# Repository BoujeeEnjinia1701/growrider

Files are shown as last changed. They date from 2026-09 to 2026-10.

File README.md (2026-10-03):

# GrowRider

     

**Area:** Mobility and Logistics · **TRL:** 3 of 9 (proof of concept on paper) · **Value-engineering target:** USD 300 (estimated USD 311 with the helmet) · **Difficulty:** 2 of 5

Rugged, repairable children's bicycle with an adjustable frame that fits ages 6 to 14, puncture-proof tires, a coaster brake and a small rated rack, built from parts common to regional adult bicycles.

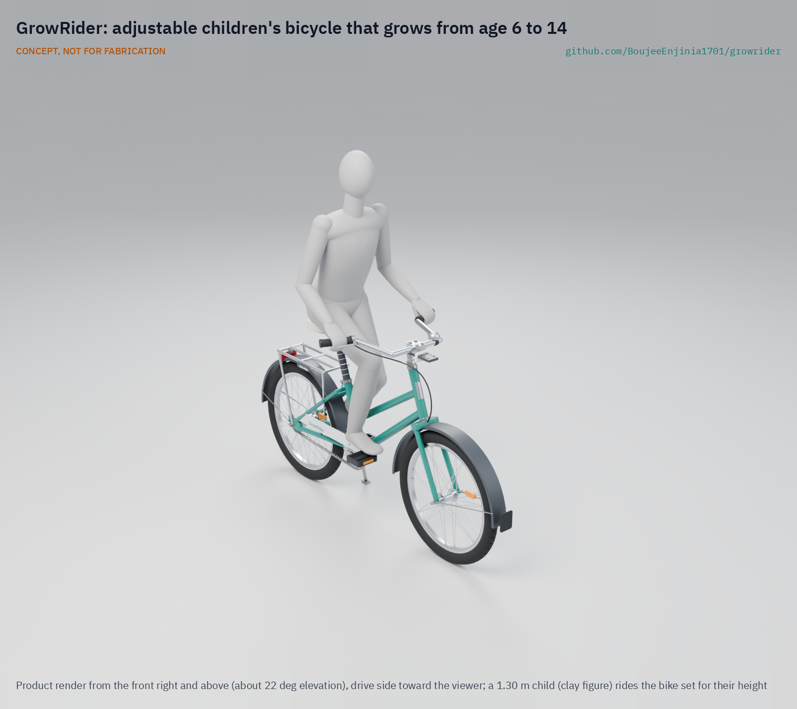
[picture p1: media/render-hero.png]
GrowRider: adjustable children's bicycle that grows from age 6 to 14, product render


[Exploded render](media/render-exploded.png) · [Detail render](media/render-detail.png) · [Interactive 3D model](media/viewer.html) · [Concept blueprint (PDF)](media/concept-blueprint.pdf) · [General arrangement GRR-DWG-001 (PDF)](cad/drawings/GRR-DWG-001.pdf) · [Sizing calculations](docs/04-calcs/01-sizing.md) · [Prototype build plan](docs/05-build-plan.md) · [Design decisions](docs/06-design-decisions.md) · [Review note](docs/REVIEW.md)

## Concept rationale

Children grow out of a fixed frame in two or three years, and in rural households one bicycle often has to serve several siblings over a decade. GrowRider answers that with adjustment instead of new frames: a two-stage telescoping seat post and a long quill stem stretch one 20 in step-through bicycle across riders from about 1.10 to 1.65 m, and the wear parts (chain, coaster hub internals, 1 in headset, 25.4 mm seat post, 9/16 in pedals) are the ones already sold for the region's adult roadsters, so any market mechanic can keep it running.

The design is open and garage-buildable because the people best placed to make and repair it are local frame builders and bicycle assemblers, not a distant factory. Publishing the geometry, the calculations and the bill of materials under CERN-OHL-S lets a school network, an NGO workshop or a regional assembler build it, change it for local parts and share the changes back.

## Burning platform

UNESCO reports that [251 million children and youth are out of school](https://www.unesco.org/en/articles/251m-children-and-youth-still-out-school-despite-decades-progress-unesco-report), that more than half of the world's out-of-school children and adolescents live in sub-Saharan Africa, and that 33 % of school-age children in low-income countries are out of school against 3 % in high-income countries. Distance is one of the barriers: in Bihar, India, a program that gave girls a bicycle to continue to secondary school raised their age-appropriate enrollment by 32 % and cut the gender gap by 40 %, with the largest effect in villages far from a school ([Muralidharan and Prakash, *American Economic Journal: Applied Economics*, 2017](https://www.aeaweb.org/articles?id=10.1257/app.20160004)).

The journey itself is dangerous. The World Health Organization reports that [road traffic injuries are the leading cause of death for children and young adults aged 5 to 29](https://www.who.int/news-room/fact-sheets/detail/road-traffic-injuries), with about 1.16 million road deaths a year, 92 % of them in low- and middle-income countries. A children's bicycle for these roads has to fit the child, stop reliably and be kept in repair, not just be cheap.

## Where it could be used

### By industry

| Industry | Use |
| --- | --- |
| Education | School bicycle fleets for rural primary and lower secondary pupils, loaned and refitted each year |
| Humanitarian and development NGOs | A children's model alongside existing adult roadster distribution and mechanic training |
| Bicycle assembly and retail | A regional children's frame built from roadster spares already in stock |
| Community health and social protection | Transport support bundled with school-feeding or cash-transfer programs |
| Local workshops and vocational training | A teaching project for frame building, wheel building and bicycle repair |

### By country or region

| Country or region | Why it matters there |
| --- | --- |
| Sub-Saharan Africa (for example Zambia, Kenya, Malawi) | More than half of the world's out-of-school children live in the region ([UNESCO](https://www.unesco.org/en/articles/251m-children-and-youth-still-out-school-despite-decades-progress-unesco-report)), and rugged adult roadsters and their spare-parts networks are already established |
| India (for example Bihar) | State bicycle programs for schoolgirls have measurably raised enrollment ([Muralidharan and Prakash, 2017](https://www.aeaweb.org/articles?id=10.1257/app.20160004)); younger pupils are not served by adult bicycles |
| Latin America (for example Bogotá, Colombia) | Bogotá's mobility and education departments run Al Colegio en Bici, which takes public-school pupils to school on guided cycle routes; in 2024 more than 9,000 students from 147 public schools used it and the city's other guided cycling and walking programs ([Alcaldía de Bogotá](https://bogota.gov.co/mi-ciudad/educacion/movilidad-en-bogota-al-colegio-en-bici-beneficios-para-estudiantes)). One adjustable frame could serve pupils of many sizes in such programs |
| Southeast Asia (for example Cambodia) | In July 2026, 200 donated bicycles went to pupils of five schools in Banteay Meanchey province, where many had walked several kilometres a day to class ([Agence Kampuchea Presse](https://www.akp.gov.kh/post/detail/374647)); a bicycle that grows with the child lasts longer in such donations |
| Netherlands and other high-income cycling countries | In a 2026 study of Dutch primary school children, 64 % cycled to school at least once a week ([Veldman, Westerbroek and Singh, *Transportation Research Interdisciplinary Perspectives*, 2026](https://doi.org/10.1016/j.trip.2026.101998)); an adjustable frame that is handed down suits families and school loan fleets and cuts the number of outgrown bikes |

## What sparked the idea

The starting point was the Chief Minister's Bicycle program in Bihar, India, launched in 2006, which gave every girl who enrolled in grade 9 Rs 2,000 (about $40) to buy a bicycle. Muralidharan and Prakash's evaluation ([*American Economic Journal: Applied Economics*, 2017](https://www.aeaweb.org/articles?id=10.1257/app.20160004); [NBER working paper 19305](https://www.nber.org/papers/w19305)) found that it raised girls' age-appropriate secondary enrollment by 32 % and worked best where the school was far from the village, so time and safety on the road were the barrier. The program reached teenagers entering secondary school, who can ride a standard bicycle. GrowRider asks what the same idea would need to reach the younger, smaller children who walk just as far: a frame that fits a six-year-old, grows to fit a fourteen-year-old, and is then handed down.

## Problem

Rural children often walk more than an hour each way to school, and adult bicycles do not fit them while imported children's bikes break quickly and cannot be repaired locally. Design with, not for: requirements must come from co-design sessions and field trials with the intended users through a local partner.

## Concept

Rugged, repairable children's bicycle with an adjustable frame that fits ages 6 to 14, puncture-proof tires, a coaster brake and a small rated rack, built from parts common to regional adult bicycles.

Full design precis: [docs/02-concept.md](docs/02-concept.md). The TRL 3 calculations ([GRR-CAL-001](docs/04-calcs/01-sizing.md)) find the fit range, reach, wheel size and rack meet their requirements on paper. With the recommendations Amish accepted on 2026-09-25 ([GRR-DDR-002](docs/decisions/0002-recommendations-accepted.md)), mass fell from 15.3 to 14.4 kg; with the parts added to make the design buildable ([GRR-DDR-003](docs/decisions/0003-design-for-construction.md)) it is 15.1 kg against the 13 kg production goal and still not met. Value-engineering target: USD 300. Estimated cost of the constructable design: USD 311 with the child helmet supplied with every bike (USD 11 over the target), USD 299 for the bike alone (USD 1 under). Braking margins for the smallest rider, the fit-change time and steerer strength are at risk.

## Key components

- Step-through frame with chromoly main tubes, a two-stage telescoping seat post (saddle 400 to 670 mm) and a long chromoly quill stem
- 20 in (ISO 406) alloy-rim wheels with solid puncture-proof tires
- Coaster brake hub plus front rim brake
- 140 mm cranks
- Single-speed chain drive
- Aluminium rear rack, rated 10 kg
- Reflectors and bell

The priced bill of materials is in [bom/bom.csv](bom/bom.csv): USD 311 with the child helmet supplied with every bike and USD 299 for the bike alone, against a USD 300 value-engineering target. The parametric model is [cad/src/model.py](cad/src/model.py), with STEP files in `cad/step/`.

## Building the prototype

The [prototype build plan](docs/05-build-plan.md) (GRR-BLD-001) shows how to make each of the eight made components, from the rear dropouts and the brazed chromoly frame to the slotted seat post, the quill stem with its head plate and the welded aluminium rack, and how to put all 24 components together in 17 steps, each with a picture drawn from the model. Making the concept buildable added track-end dropouts, stop screws in the seat post collars, a two-position bar clamp on a head plate and fixings for the rack, fenders, kickstand and chainguard, recorded in [GRR-DDR-003](docs/decisions/0003-design-for-construction.md). A local frame builder can make the components and any bicycle mechanic can assemble them. Decisions still open are in the [design decisions register](docs/06-design-decisions.md). Nobody may ride the prototype until it has passed the ISO 4210-2 tests.

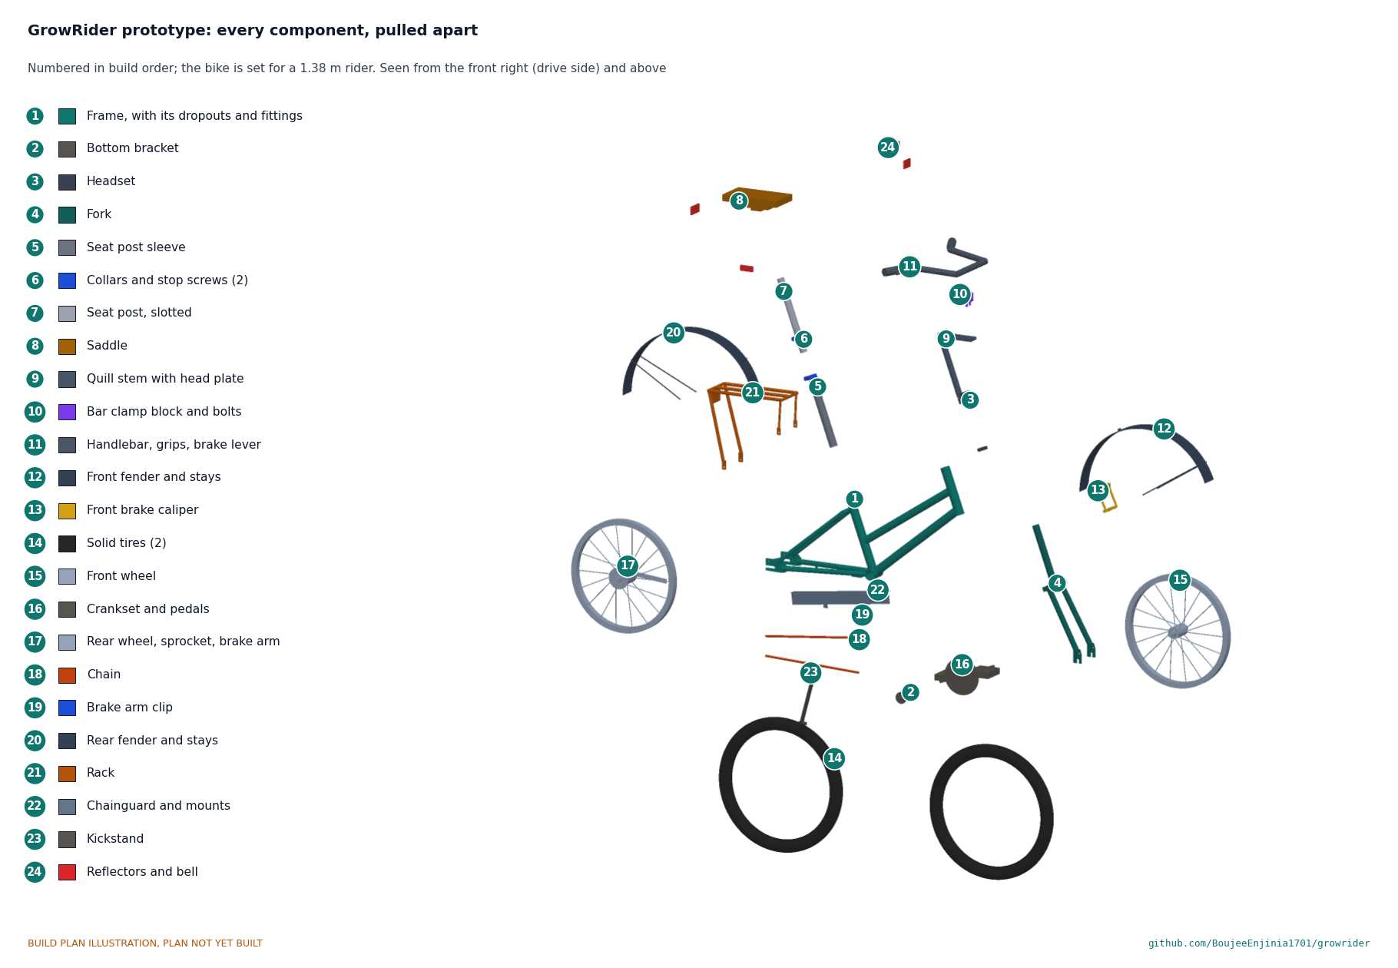
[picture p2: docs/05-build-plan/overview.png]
GrowRider prototype: every component, pulled apart and numbered in build order


## Safety

> **Safety:** Nothing has been built or tested. Rack load is limited to 10 kg for child safety. Frame, fork, seat post, stem and brakes must pass the tests of ISO 4210-2 (the standard that applies by saddle height) before anyone rides it.

## Repository layout

| Folder | Contents |
| --- | --- |
| `docs/` | Problem, concept, requirements, calculations and design decisions |
| `cad/src/` | build123d Python source, the source of truth for all geometry |
| `cad/step/`, `cad/stl/` | Exported models for FreeCAD, other CAD tools and printing |
| `cad/drawings/` | 2D sketches and dimensioned drawings |
| `bom/` | Bill of materials |
| `electronics/` | KiCad schematics and PCB layouts |
| `firmware/` | Microcontroller code |
| `media/` | Renders, perspectives and photos |
| `build-log/` | Dated prototyping notes |

## Documentation

Controlled documents follow the portfolio [documentation standard](.kit/STANDARDS.md). Each carries a document ID (GRR-PRC-001 for the precis), a version and a revision history. Branded PDFs are built with `python .kit/render.py` and attached to GitHub Releases when a document is tagged, for example `GRR-PRC-001/v1.0`.

## Credits

Designed by Amish Chadha. See [CONTRIBUTORS.md](CONTRIBUTORS.md) for roles. To cite this design, use [CITATION.cff](CITATION.cff) (GitHub shows it as "Cite this repository").

AI assistance (Claude) was used to accelerate concept renders, prototype documentation and first-pass sizing calculations. Design direction and all decisions are Amish Chadha's, recorded in this repository's decision records (`docs/decisions/`).

## Licenses

- **Hardware** (CAD, drawings, BOM, electronics): [CERN-OHL-S v2](LICENSE)
- **Software** (firmware, scripts, notebooks): [MIT](LICENSE-SOFTWARE)

A project of the [Design Molecule](https://designmolecule.com) lab.

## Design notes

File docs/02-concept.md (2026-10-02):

---
doc_id: GRR-PRC-001
title: GrowRider design precis
project: GrowRider
doc_type: Design precis
version: "0.8"
status: Draft
date: '2026-10-02'
author: Amish Chadha
license: CERN-OHL-S-2.0
revisions:
- version: "0.1"
  date: '2026-09-24'
  author: Amish Chadha
  change: Initial scaffold
- version: "0.2"
  date: '2026-09-24'
  author: Amish Chadha
  change: Populate to TRL 2 (architecture, first-order numbers, design choices, safety, media)
- version: "0.3"
  date: '2026-09-25'
  author: Amish Chadha
  change: TRL 3 (decisions of GRR-DDR-001 recorded; numbers replaced by GRR-CAL-001; seat post, stem and head tube sized; model, drawing GRR-DWG-001 and media updated)
- version: "0.4"
  date: '2026-09-25'
  author: Amish Chadha
  change: Recommendations accepted by Amish (DDR-002)
- version: "0.5"
  date: '2026-09-26'
  author: Amish Chadha
  change: Budget top-up approved by Amish
- version: "0.6"
  date: '2026-10-01'
  author: Amish Chadha
  change: Constructable design (GRR-DDR-003); cost stated against the value-engineering target
- version: "0.7"
  date: '2026-10-01'
  author: Amish Chadha
  change: GRR-DDR-003 accepted by Amish; quill insertion mark with a bright painted band, painted height scales, frame color and chainguard name as decided
- version: "0.8"
  date: '2026-10-02'
  author: Amish Chadha
  change: Helmet supplied with every bike, World Bicycle Relief as first candidate partner and Zambia as first candidate region, as decided by Amish on 2026-10-02 (GRR-DEC-001 v0.3)
---

# GrowRider design precis

GrowRider is a step-through chromoly steel children's bicycle on 20 in wheels whose seat post and stem telescope, so one bike fits riders from about 1.10 to 1.65 m (ages about 6 to 14) and can be handed down between siblings. It uses a coaster brake plus a front rim brake, puncture-proof tires, a single-speed chain drive and a small rack rated 10 kg, with wear parts shared with the region's adult roadsters. The calculation note GRR-CAL-001 v0.4 shows on paper that the fit range, reach, wheel size and rack meet their requirements; mass (about 15.1 kg against the 13 kg production goal) is not met; against the USD 300 value-engineering target, the constructable design is estimated at USD 299 for the bike (USD 1 under) and USD 311 with the helmet (USD 11 over), and the production cost is not yet estimated; and braking margins for the smallest rider, the fit-change time and steerer strength are at risk. Wheel size, brakes, frame type, tires and crank length were decided by Amish on 2026-09-25 (GRR-DDR-001), and on the same day he accepted the TRL 3 recommendations: chromoly main tubes, steerer, quill and sleeve, an aluminium rack, alloy rims and bar, a wider R2 and a split R9 (GRR-DDR-002). The design was made constructable on 2026-10-01 (GRR-DDR-003, accepted by Amish on 2026-10-01), and the prototype build plan is GRR-BLD-001 (`docs/05-build-plan.md`).

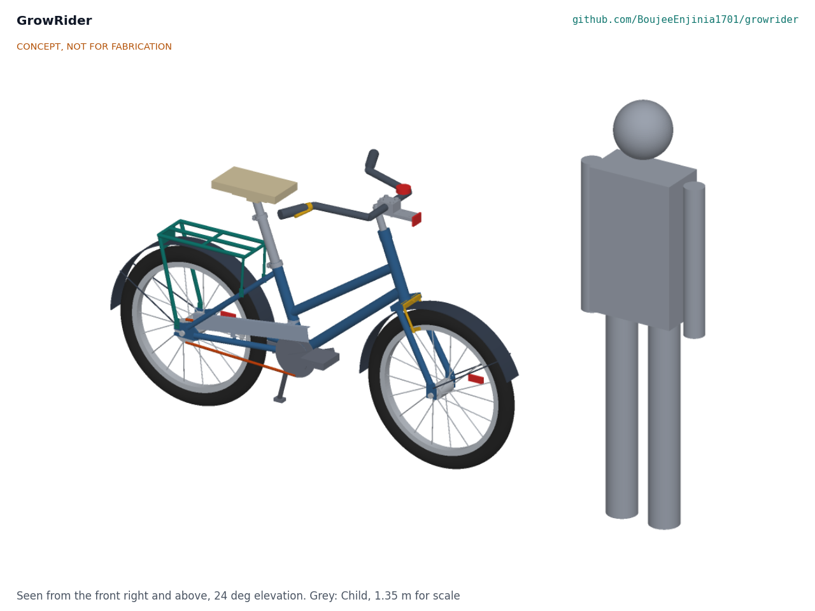
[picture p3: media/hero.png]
Hero render


*Figure 1. GrowRider parametric model (`cad/src/model.py`) set for a 1.38 m rider, beside a 1.35 m child (about 10 years old) for scale.*

## How it works

1. **Fit the rider.** A parent, teacher or mechanic sets saddle height with a two-stage telescoping seat post (a 29.2 x 1.8 mm chromoly sleeve that slides 130 mm in the 31.8 mm seat tube, then a standard 25.4 mm seat post that slides 140 mm in the sleeve) and sets handlebar height with a long 22.0 mm quill stem that slides 120 mm in the 1 in fork steerer; the bar clamp bolts to the quill's head plate 45 or 105 mm ahead of the steering axis. Each sliding part keeps at least 100 mm of insertion, shown by a permanent mark; on both seat post stages a stop screw in the clamp collar, riding in a slot, stops the part at that point. All the fit clamps use 13 mm bolts.
2. **Ride to school.** The rider pedals a single-speed chain drive (32T chainring, 18T sprocket, 140 mm cranks) at about 65 rpm for 11 km/h. Solid or airless tires cannot go flat on thorns.
3. **Stop.** Pedaling backward engages the coaster brake in the rear hub. A front rim brake with a short-reach lever gives a second, independent brake that still works if the chain comes off.
4. **Carry a school bag.** A small rear rack, rated and marked 10 kg, carries a bag or books. It is sized for a bag, not a passenger or a water container.
5. **Grow and hand down.** As the child grows, the post and stem are raised. When the child moves to an adult roadster, both are lowered and the bike passes to a younger sibling. Worn parts are replaced from the roadster parts already sold in the local market.

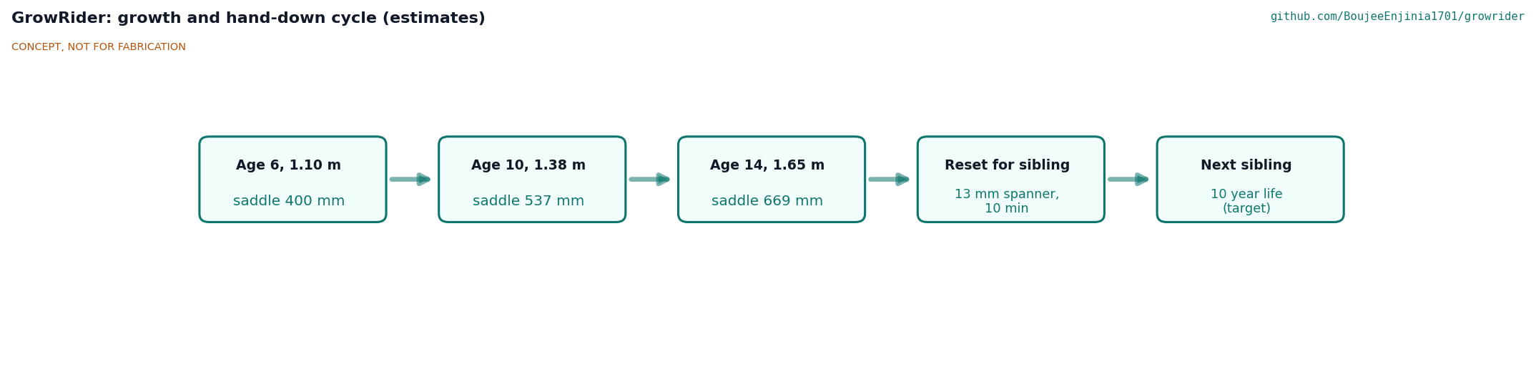
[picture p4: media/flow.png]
Growth and hand-down cycle


*Figure 2. Growth and hand-down cycle. Saddle heights are estimates from the crank-corrected fit rule in GRR-CAL-001, Table 2; the 10-year life is a target.*

## Main components

Item numbers match the exploded view (Figure 3) and `bom/bom.csv`.

| # | Component | Choice | Notes |
| --- | --- | --- | --- |
| 1 | Frame | Step-through frame with twin down tubes; chromoly 4130 main tubes: 31.8 x 1.2 mm seat tube, 280 mm long; 31.8 x 0.9 mm down tube; 28.6 x 0.9 mm loop tube; 180 mm head tube; steel stays | Decided 2026-09-25 (D3, D7). Low stepping point (455 mm) for small riders and school skirts |
| 2 | Fork | 20 in fork, 30 mm offset, crown about 16 mm deep, slotted fork ends 100 mm apart, 1 in threaded chromoly steerer with 220 mm usable above the crown (D10) | Standard 1 in headset as on roadsters; steerer longer than a stock 20 in fork |
| 3 | Telescoping seat post | 29.2 x 1.8 mm chromoly sleeve, 250 mm long (D10), plus 25.4 mm seat post, 280 mm long | 270 mm of travel in two stages (130 and 140 mm); saddle 400 to 670 mm from the BB |
| 4 | Saddle | Child size, light color cover | Light color stays cooler in sun |
| 5 | Telescoping stem | Long 22.0 mm chromoly quill (240 mm), 120 mm travel, welded head plate with a bolt-on bar clamp block at 45 or 105 mm ahead of the steering axis | Adjusts bar height (113 mm) and reach |
| 6 | Handlebar and grips | 22.2 mm alloy swept-back bar (D7), 520 mm wide, 160 mm sweep | Upright position for visibility |
| 7 | Front wheel | 20 in (ISO 406) alloy rim (D8), 28 spokes, nutted axle | Decided 2026-09-25 (D1); 15 mm axle nuts as on roadsters |
| 8 | Rear wheel | 20 in (ISO 406) alloy rim (D7) with coaster brake hub | Hub type widely used on regional roadsters (to confirm) |
| 9 | Tires (2) | 20 x 1.95 in solid or airless | Decided 2026-09-25 (D4) |
| 10 | Crankset | 140 mm cranks, 32T ring, 9/16 in pedal threads | One length decided 2026-09-25 (D5); adult pedals fit |
| 11 | Chain and sprocket | 1/2 x 1/8 in chain, 18T sprocket | Same chain as roadsters |
| 12 | Front brake | Side-pull caliper, short-reach adjustable lever | Second, independent brake; decided 2026-09-25 (D2) |
| 13 | Rear rack | 12 x 1.5 mm aluminium 6061-T6 tube (D7), 300 x 120 mm platform at 545 mm, 10 kg marked | No footrests or passenger seat |
| 14 | Fenders | Pair, full coverage | Rainy-season mud and school uniforms |
| 15 | Chainguard | Full plate over the upper chain run | Keeps clothing out of the chain |
| 16 | Kickstand | Rear-mounted | Parking at school |
| 17 | Reflectors and bell | Front white, rear red, spoke and pedal reflectors, bell | Road visibility |

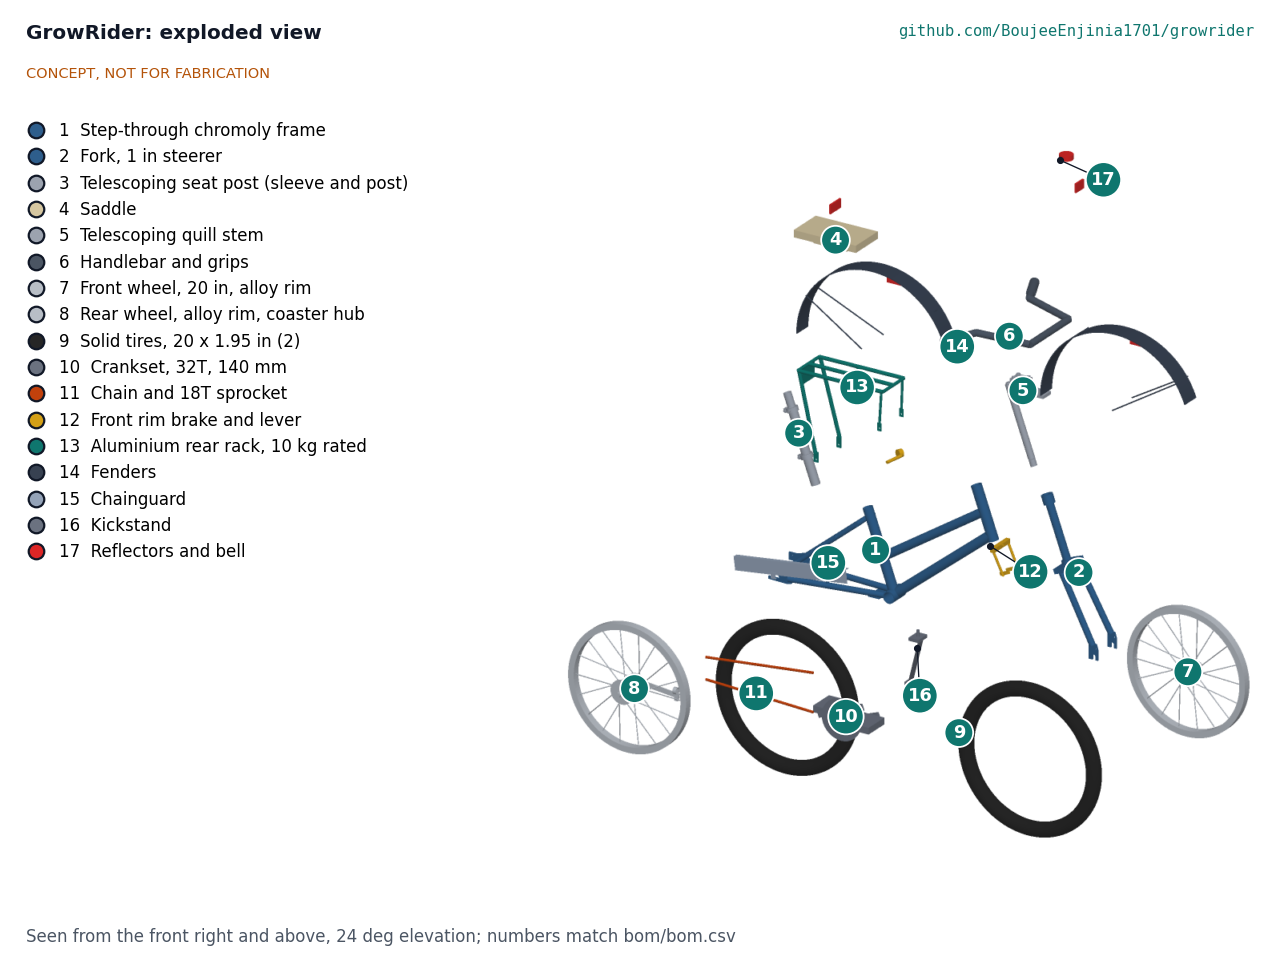
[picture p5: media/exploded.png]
Exploded view


*Figure 3. Exploded view with item numbers matching the BOM. The bottom bracket, headset, hardware and helmet (BOM lines 18 to 20) are not modeled.*

## Key numbers

All values come from the calculation note GRR-CAL-001 v0.3 and its script `docs/04-calcs/sizing.py`; they are paper estimates. The general arrangement is drawing GRR-DWG-001 (`cad/drawings/GRR-DWG-001.pdf`).

**Fit.** Assumptions: inseam is about 0.45 times standing height. Rule A sets saddle height (BB center to saddle top) at 0.88 times inseam; rule B sets saddle top to pedal at the bottom of the stroke at 1.09 times inseam, which accounts for the 140 mm crank. The design covers both.

| Rider height | Inseam (0.45 x height) | Saddle height, rule A | Saddle height, rule B |
| --- | --- | --- | --- |
| 1.10 m (about age 6) | 495 mm | 436 mm | 400 mm |
| 1.38 m (about age 10) | 621 mm | 546 mm | 537 mm |
| 1.65 m (about age 14) | 742 mm | 653 mm | 669 mm |

Table 1. Saddle height across the fit range (GRR-CAL-001, Table 2).

| Quantity | Value | Basis | Requirement |
| --- | --- | --- | --- |
| Saddle height range | 400 to 670 mm (270 mm) | Two stages of 130 and 140 mm, 100 mm insertion each | R2 met |
| Saddle rise and setback over the range | 254 mm up, 92 mm back | 270 mm along a 70° seat axis | |
| Handlebar height range | 113 mm | 120 mm of quill travel along a 70° steering axis | R3 met |
| Reach adjustment | 141 mm (241 mm shortest, 382 mm longest) | Seat and steering geometry, two bar clamp positions 60 mm apart, ±15 mm saddle rail | R3 met; shortest is 21 mm above the 220 mm placeholder for a 1.10 m rider |
| Standover at the stepping point | 455 mm | Loop tube top 100 mm ahead of its seat-tube joint | R1 met; 40 mm below a 1.10 m rider's inseam |
| Saddle top above ground | 636 to 890 mm | 260 mm BB height | Classifies the bike under ISO 4210-2 (city and trekking) |
| Grips relative to saddle | +128 mm (smallest) to -13 mm (largest) | 180 mm head tube needed for quill insertion | Very upright for small riders |
| Trail | 59 mm | 70° head angle, 30 mm fork offset | |
| Pedal clearance | 109 mm; strike at about 32° lean | 260 mm BB, 140 mm cranks | |
| Toe overlap | None (1.10 m) to 19 mm (1.65 m) with the bar turned | 480 mm front center | Tell riders |
| Gear development | 2.79 m per crank turn | 32/18 on a 1.57 m rolling circumference | 66 rpm at 11 km/h |
| Power on the level at 11 km/h | 26 to 51 W (34 W at 1.38 m) | Rolling coefficient 0.02 (solid tire on gravel), CdA 0.35 m² | Sustainable for a child |
| Power on a 5 % climb at 7 km/h | 47 to 102 W (64 W at 1.38 m) | Same, plus gravity | Short climbs only; steep hills walked |
| Mass | 15.1 kg (14.4 kg before GRR-DDR-003, 15.3 kg before GRR-DDR-002) | Frame 2.67 kg from the model's tubes and fittings, stem 0.90 kg, wheels 2.75, solid tires 2.2, drive 1.45, rack 0.44, other parts 5.1 kg | **R5 (13 kg production goal) not met** |
| Rear coaster brake alone, grip limit | 0.26 to 0.28 g dry, 0.19 g on loose gravel | μ (L - x) / (L + μh) with the rider-plus-bike mass center | Front brake needed on gravel |
| Coaster brake, smallest rider | 0.22 g | 85 N back-pedal force needed for 0.2 g, about 93 N available (assumed hub brake ratio 2.5) | R7 at risk |
| Front rim brake, smallest rider | 0.24 g dry; about 0.14 g wet with the alloy rim (0.05 g with steel) | 33 N lever force for 0.2 g dry, 40 N assumed | R7 at risk; alloy rim decided (D8) |
| Both brakes, dry | 0.46 to 0.57 g | Sum, capped by grip and pitch-over (0.57 to 0.81 g) | R7 target 0.35 g met on paper |
| Rack | 10 kg; 26 MPa in the aluminium rails at 2.5 g (110 MPa welded 6061-T6) | 300 x 120 mm platform; front wheel load falls from 40 % to 32 % with 10 kg for the smallest rider | R6 met |
| Strength screen | 1 of 7 sections above its screen: steerer at the crown in hard braking (117 MPa against 90 MPa for chromoly); sleeve 61 MPa, quill 79 MPa, head plate 71 MPa and seat tube 72 MPa pass (3 of 6 above before GRR-DDR-002) | Largest rider, largest setting | R12 at risk |
| Prototype parts cost | USD 311 with the helmet supplied with every bike, USD 299 for the bike alone (USD 293 and 281 before GRR-DDR-003) | `bom/bom.csv` | Value-engineering target USD 300: bike USD 1 under, with helmet USD 11 over; R11 at risk until production cost is estimated |

**Commute time.** Assumptions: a 5 km trip each way; walking at 4 to 5 km/h; cycling at 10 to 12 km/h on dirt roads.

| Mode | Speed | One way | Round trip |
| --- | --- | --- | --- |
| Walking | 4 to 5 km/h | 60 to 75 min | 2.0 to 2.5 h |
| GrowRider | 10 to 12 km/h | 25 to 30 min | 50 to 60 min |
| Time returned to the child | | 30 to 50 min | 60 to 100 min per day; about 79 min per day and 249 h per 190-day school year at the midpoints |

Table 2. School trip time, walking and cycling (estimates).

## Key design choices

- **Wheel size: 20 in (ISO 406).** 20 in keeps standover at 455 mm so a 1.10 m child can stand over the frame, and gives lower mass. 24 in (ISO 507) rolls better on ruts but raises standover to about 510 mm and fails R1 for the smallest riders. Neither is a regional roadster size, so tires and rims are the one commonality gap either way. Decided by Amish, 2026-09-25 (GRR-DDR-001, D1).
- **Brakes: coaster brake plus front rim brake.** A coaster brake is simple, weather-proof, needs no hand strength, and uses hub internals common on regional roadsters. On its own it fails completely if the chain comes off and is marginal on loose gravel (about 0.19 g). Adding a front rim brake gives two independent brakes. Alternatives: coaster only (cheaper, one failure mode away from no brake) or two hand brakes without a coaster (needs hand strength small children may lack). Decided by Amish, 2026-09-25: coaster plus front rim brake (GRR-DDR-001, D2). GRR-CAL-001 finds the smallest rider's margins small and a wet steel rim nearly useless, so an alloy front rim was decided (GRR-DDR-002, D8), and the coaster hub's brake ratio is to be obtained before further brake work (D9).
- **Step-through frame.** Lower standover than a diamond frame, and practical for school uniforms and skirts. It needs twin down tubes to keep the frame stiff. Decided by Amish, 2026-09-25 (GRR-DDR-001, D3).
- **Mass and materials.** Chromoly 4130 main tubes, an aluminium rack, alloy rims and an alloy bar, keeping the solid tires, with 13 kg kept as the production goal. Decided by Amish, 2026-09-25: go with recommendation (GRR-DDR-002, D7). The result was 14.4 kg, not the 13.6 kg first estimated, and it added USD 38 to the prototype; with the parts added for construction (GRR-DDR-003) the bike is 15.1 kg.
- **Sliding parts and steerer.** Chromoly steerer and quill and a 29.2 x 1.8 mm chromoly sleeve, which needs a 1.2 mm seat tube wall to fit. Decided by Amish, 2026-09-25: go with recommendation (GRR-DDR-002, D10). The steerer is still above its screen in hard braking; a 2.0 mm wall is proposed (N2).
- **Puncture-proof tires.** Solid or airless tires remove thorn punctures entirely but add about 0.5 kg for the pair (GRR-CAL-001), ride harsher and roll less freely. Thorn-resistant tubes with tire liners keep standard parts and a softer ride, but still puncture occasionally. Decided by Amish, 2026-09-25: solid or airless for the prototype, and ask users in co-design (GRR-DDR-001, D4).
- **Parts commonality.** Chain, coaster hub internals, 1 in headset, 25.4 mm seat post, 22.2 mm handlebar and 9/16 in pedal threads are chosen to match adult roadster parts. Children's bikes often use 1/2 in pedal threads; GrowRider does not.
- **Head tube and steerer length.** A 180 mm head tube and 30 mm headset stack give the quill 220 mm of steerer, enough for 120 mm of travel with 100 mm of insertion at full height. The cost is a high bar for the smallest rider (128 mm above the saddle).
- **Bolted clamps, not quick releases.** 13 mm bolts discourage casual changes and theft of the seat post, and every mechanic already has the spanner.

## Safety

> **Safety:** GrowRider is ridden by children on roads shared with trucks and motorbikes. It is a concept. No part of it has been built or tested, and it must not be ridden until the frame, fork, sliding joints, rack and brakes have passed the tests of the applicable standard (ISO 8098 or ISO 4210) at a later TRL.

- **Brakes.** Two independent brakes are required (R7). The coaster brake stops working if the chain comes off, so the front brake is not optional. Small hands need a short-reach lever. Riders need to be shown that a hard front brake on loose gravel can skid the front wheel. A wet steel rim gives a child almost no front braking (about 0.05 g), so an alloy rim is specified (about 0.14 g wet).
- **Telescoping parts.** A seat post or stem raised past its minimum insertion can break or pull out. Every sliding part carries a permanent minimum insertion mark at 100 mm. On the sleeve and the seat post a stop screw in the clamp collar, riding in a slot, stops the part at that point (GRR-DDR-003, P8). The quill cannot take a stop of this kind inside a threaded steerer, so for the prototype its minimum insertion mark, with a bright painted band above it, is its only limit, checked at every fit change; a clamp-on stop collar is to be considered after the fit trials (decided by Amish, 2026-10-01, GRR-DEC-001). Painted height scales on the exposed sleeve and quill let a setting be noted and reset. At full extension the sleeve and quill are the most stressed sections (GRR-CAL-001, section K). Clamp slots are pinch points for fingers.
- **Rack limit.** The rack is rated 10 kg and marked. It must not carry passengers, water containers or goods above the rating: a heavy load high over the rear wheel makes a light bike hard for a child to steer and can lift the front wheel. The rack is sized for a school bag, with no footrests.
- **Road visibility.** School trips often start and end near dawn or dusk. Front white, rear red, spoke and pedal reflectors are fitted. The portfolio renders use the kit teal; the production frame color is settled in co-design, with a high-visibility option (decided by Amish, 2026-10-01). A light (for example a hub dynamo) is suggested for a later version.
- **Helmet.** An adjustable, ventilated child helmet is supplied with every bike through the partner program and fitted at handover (BOM line 20; decided by Amish, 2026-10-02, GRR-DEC-001). Hot-climate comfort will decide whether it is worn, so how it is worn is discussed in co-design.
- **Aluminium rack.** Welded aluminium has a low fatigue strength and cracks without warning; the rack must pass static and fatigue tests before use, and the 10 kg rating marking matters more than before.
- **Clothing and hot surfaces.** The chainguard keeps skirts and trousers out of the chain. A light saddle cover limits heating in the sun.
- **Mass.** At about 15.1 kg, the bike is about 80 % of the weight of a 19 kg six-year-old. This makes pushing, lifting and controlling a fall harder for the smallest riders, and is the reason R5 matters.

## Open questions

- Reduce mass toward the 13 kg production goal: with chromoly, aluminium and alloy parts adopted (D7) and the parts added for construction (GRR-DDR-003), the bike is 15.1 kg. The remaining option, pneumatic tires with liners (0.5 kg), would reverse D4. Can local frame builders work chromoly and weld aluminium, and are the lighter parts stocked?
- Low bar option: would a flat bar suit the smallest riders, whose grips sit 128 mm above the saddle? A co-design question (GRR-DDR-002, D13).
- Sliding joints in dust and rain: will greased steel sleeves seize over years of use? Would a split collar with a wiper seal or a plastic bushing help?
- Crank length: one 140 mm length for the prototype was decided on 2026-09-25 (D5). It is 0.28 of a 1.10 m rider's inseam; the 127 mm swap remains a later option.
- Standard: by maximum saddle height (890 mm) GrowRider falls under ISO 4210-2 (city and trekking). Its test loads assume adult riders; whether to also meet ISO 8098 limits for the small settings needs the standards' text.
- Confirm with a partner which roadster parts are actually stocked in the target region, including coaster hubs and 20 in tires. World Bicycle Relief is the first candidate partner to approach and Zambia the first candidate region (decided by Amish, 2026-10-02, GRR-DEC-001).
- Test the anthropometric assumptions (inseam ratio, reach) with measurements of children in the target region, where average heights may be below global references.

Concept media: [blueprint sheet](../media/concept-blueprint.pdf), [interactive 3D model](../media/viewer.html).

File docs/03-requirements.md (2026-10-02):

---
doc_id: GRR-REQ-001
title: GrowRider requirements
project: GrowRider
doc_type: Requirements
version: "0.7"
status: Draft
date: '2026-10-02'
author: Amish Chadha
license: CERN-OHL-S-2.0
revisions:
- version: "0.1"
  date: '2026-09-24'
  author: Amish Chadha
  change: Initial scaffold
- version: "0.2"
  date: '2026-09-24'
  author: Amish Chadha
  change: First measurable requirements for TRL 2
- version: "0.3"
  date: '2026-09-25'
  author: Amish Chadha
  change: Record decisions of GRR-DDR-001 (20 in wheels, brakes, $120 production target); add TRL 3 status from GRR-CAL-001
- version: "0.4"
  date: '2026-09-25'
  author: Amish Chadha
  change: Recommendations accepted by Amish (DDR-002)
- version: "0.5"
  date: '2026-09-26'
  author: Amish Chadha
  change: Budget top-up approved by Amish
- version: "0.6"
  date: '2026-10-01'
  author: Amish Chadha
  change: Status figures from GRR-CAL-001 v0.4 (constructable design, GRR-DDR-003); R11 stated against the value-engineering target
- version: "0.7"
  date: '2026-10-02'
  author: Amish Chadha
  change: R11 status reports USD 311 with the helmet, now supplied with every bike (decided by Amish, 2026-10-02), as the prototype figure
---

# GrowRider requirements

These are the requirements for the concept. They were checked by calculation at TRL 3 in GRR-CAL-001 v0.4, on the constructable design of GRR-DDR-003: 5 are met on paper, 1 is not met (R5, mass), 4 are at risk and 2 cannot be verified at TRL 3. Amish's acceptance of the TRL 3 recommendations on 2026-09-25 (GRR-DDR-002) widened R2 to the crank-corrected fit range, split R9 into parent and mechanic tool lists, restated R5 as the production goal and named the alloy front rim in R7. All targets must still be revised from co-design findings before the design is frozen (see GRR-PRB-001).

| ID | Requirement | Target | Verification (TRL 3 or later) | TRL 3 status (GRR-CAL-001) |
| --- | --- | --- | --- | --- |
| R1 | Fit the intended riders | Rider height 1.10 to 1.65 m (ages about 6 to 14); standover height 470 mm or less at the stepping point | Fit calculation from anthropometric data; later fit trials with children | Met: standover 455 mm |
| R2 | Adjustable saddle height | 400 to 670 mm from bottom bracket center to saddle top (270 mm range), with at least 100 mm insertion at every sliding joint across the range (widened from 436 to 654 mm, GRR-DDR-002, D11) | Geometry calculation; massing model | Met: 400 to 670 mm, 100 mm insertion |
| R3 | Adjustable reach and handlebar height | Handlebar height adjustable by 100 mm or more; horizontal saddle-to-grip reach adjustable by 100 mm or more | Geometry calculation | Met: bar 113 mm, reach 141 mm |
| R4 | One wheel size across the whole fit range | Single wheel size for all riders: 20 in (ISO 406), decided 2026-09-25 (GRR-DDR-001, D1) | Design review; fit calculation | Met: 20 in |
| R5 | Light enough for the smallest rider to handle | Production goal: complete bike with rack, fenders and kickstand 13 kg or less; the prototype estimate is tracked against it (GRR-DDR-002, D7) | Mass estimate, then weighing | **Not met: 15.1 kg** (14.4 kg before the parts added for construction, GRR-DDR-003; 15.3 kg before D7) |
| R6 | Small, clearly rated rear rack | Rated 10 kg, rating marked on the rack; platform no larger than a school bag (about 300 x 140 mm); no passenger footrests | Design review; later static load test | Met by design: 300 x 120 mm |
| R7 | Two independent brakes a child can operate | Rear coaster brake plus front rim brake (decided 2026-09-25, GRR-DDR-001, D2), with an alloy front rim for wet braking (GRR-DDR-002, D8); each brake alone 0.2 g or more and both together 0.35 g or more on a dry, level surface; hand lever reach adjustable for small hands | First-order braking calculation; later tests to ISO 8098 or ISO 4210 as applicable | At risk: small margins for the smallest rider; wet steel rim poor |
| R8 | Puncture resistance | No loss of use from thorn punctures; tire life 2,000 km or more (about one school year of 10 km per day) | Supplier data; later field trial | Not verifiable at TRL 3 (tire life) |
| R9 | Serviceable with basic tools (split by GRR-DDR-002, D12) | R9a, parent or teacher: every fit adjustment with a 13 mm spanner and a screwdriver, and a fit change in 10 minutes or less. R9b, mechanic: all routine service, including headset and bottom bracket, with 13, 15 and 32 mm spanners, a bottom bracket lockring spanner and a screwdriver | Design review; later timed trial | At risk: both tool lists met; fit change 10 min, at the limit |
| R10 | Parts commonality with regional adult roadsters | Every wear part except tires and rims interchangeable with regional roadster parts (chain, sprocket, coaster hub internals, bottom bracket, headset, pedals, seat post, handlebar, brake blocks) | BOM review against a regional parts list from the partner | Not verifiable at TRL 3 (no regional parts list) |
| R11 | Low cost | Prototype parts cost reported against the USD 300 value-engineering target in `project.yaml` (a hypothetical control target, not a limit; Amish, 2026-10-01; raised from USD 250 on 2026-09-26, GRR-DDR-002, N1); production cost target USD 120 or less per bike at volume (decided 2026-09-25, GRR-DDR-001, D6) | Priced BOM; production estimate with a regional assembler | At risk: USD 311 with the helmet supplied with every bike (USD 11 over the target; decided by Amish, 2026-10-02), USD 299 for the bike alone (USD 1 under); USD 120 production cost not yet estimated |
| R12 | Lasts across siblings | 10-year service life for at least three successive riders; frame and fork sized for a 60 kg rider plus a 10 kg rack load; sliding joints that do not seize in dust and rain | Fatigue calculation at TRL 3; later frame fatigue tests | At risk: 1 of 7 sections above the fatigue screen (steerer; 3 of 6 before GRR-DDR-002) |

## Assumptions

- Inseam is about 0.45 times standing height, and a comfortable saddle height (bottom bracket center to saddle top) is about 0.88 times inseam. Both are common bicycle fitting rules of thumb for adults and older children and must be checked against measurements of the intended users.
- Horizontal saddle-to-grip reach for an upright riding position scales with torso and arm length, estimated at about 0.2 times height (220 mm at 1.10 m, 330 mm at 1.65 m). This is a placeholder until fit measurements are taken.
- A typical school trip is 5 km each way on dirt or gravel, ridden at 10 to 12 km/h.
- A 1.65 m rider is assumed to weigh up to 60 kg, including a margin for older teenagers.
- Saddle height (R2) is measured from the BB center to the saddle top along the seat axis. GRR-CAL-001 also checks a second fitting rule that accounts for the 140 mm crank (saddle top to pedal at 1.09 times inseam), which asks for 400 to 669 mm. R2 now takes the wider range, which covers both rules.
- Applicable standard: classified by its maximum saddle height above the ground (about 890 mm), GrowRider falls under ISO 4210-2 as a city and trekking bicycle; ISO 8098 covers maximum saddle heights below 635 mm (GRR-CAL-001, section M).

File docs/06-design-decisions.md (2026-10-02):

---
doc_id: GRR-DEC-001
title: GrowRider design decisions register
project: GrowRider
doc_type: Design decisions register
version: "0.3"
status: Draft
date: '2026-10-02'
author: Amish Chadha
license: CERN-OHL-S-2.0
revisions:
- version: "0.1"
  date: '2026-10-01'
  author: Amish Chadha
  change: Register opened with the open decisions from REVIEW.md, GRR-DDR-001 to 003 and the build plan work
- version: "0.2"
  date: '2026-10-01'
  author: Amish Chadha
  change: Amish accepted the recommendations of open items 1 to 4 and 8 to 11 (GRR-DDR-003 accepted); moved to decisions made; open items renumbered 1 to 3
- version: "0.3"
  date: '2026-10-02'
  author: Amish Chadha
  change: Amish approved the recommendations for open items 1 to 3 on 2026-10-02 (helmet supplied with every bike, World Bicycle Relief as first candidate partner, Zambia as first candidate region); moved to decisions made; USD 311 with the helmet reported as the prototype figure
---

# GrowRider design decisions register

Every design decision still to be made, and every decision made, in one place. Each decision is argued in full in its decision record under `docs/decisions/`; this register is the index Amish works from. The build plan (`docs/05-build-plan.md`, GRR-BLD-001) describes the design as it stands and does not list open decisions.

## Open decisions

None. All open decisions were decided on 2026-10-02.

## To confirm when parts are bought

| # | What to confirm | Why it matters | Source |
| --- | --- | --- | --- |
| 1 | The coaster brake hub is 110 mm over the locknuts with its sprocket on a 42 mm chain line, and its brake ratio (hub torque to sprocket torque) | The dropouts are 110 mm apart and the chainstays are placed for a 42 mm chain line; braking for the smallest rider rests on an assumed ratio of 2.5 | GRR-DDR-003, P1 and P16; GRR-DDR-002, D9 |
| 2 | A long-reach side-pull caliper whose reach covers about 84 mm is stocked. If none is, the fallback is a fork with brake bosses and a short-pull V-brake for children's levers, which is a design decision | The crown height and tire size set the reach | GRR-DDR-003, P14 |
| 3 | The fork: crown no deeper than 16 mm, 1 in threaded steerer 25.4 x 1.6 mm with 220 mm usable above the crown, slotted fork ends 100 mm apart with eyelets, crown hole for the caliper bolt | The front fender passes 7 mm under the crown; the quill needs the full steerer length | GRR-DDR-003, P2 and P13 |
| 4 | The solid tire's real width is 50 mm or less on the rim | The rear tire clears the chainstays by 4 mm at a 48 mm width | GRR-DDR-003, P16 |
| 5 | A 29.8 mm clamp collar closes firmly on the 29.2 mm sleeve, or one is turned to 29.2 mm | Sleeve collars are not a stock size | GRR-DDR-003, P8 |
| 6 | The 22.0 x 2.0 mm chromoly tube slides in the steerer bore with about 0.2 mm clearance | Steerer bores vary by maker | GRR-DDR-003, P5 |
| 7 | The 29.2 mm sleeve slides in the seat tube after reaming to 29.4 mm, and the 25.4 mm post in the sleeve | Drawn tube bores vary by about 0.1 mm | GRR-CAL-001, A |
| 8 | A 22.2 mm roadster-style bar of about 205 mm sweep and 15 mm rise is stocked | The grips sit where the fit calculation puts them only with this sweep and rise | GRR-DDR-003, P6 |
| 9 | 1 in JIS press-in headset (30.0 mm cups) and a 68 mm BSA bottom bracket are the regional standard | The head tube bore and BB shell are made to them | GRR-DDR-003, P4 |
| 10 | A builder who can TIG weld 6061 aluminium for the rack, or a bought rack of the same size and rating | Welded aluminium needs skill and has low fatigue strength | GRR-DDR-002, D7 |
| 11 | Masses of the tires, rims, hub and bought fittings | The mass estimate uses catalog values | GRR-CAL-001, D |
| 12 | Which parts are actually stocked in the first region (Zambia, the first candidate), including coaster hubs and 20 in solid tires | Parts commonality (R10) | GRR-REQ-001, R10 |

## Value engineering

Value-engineering target: USD 300 (a hypothetical control target, not a limit; Amish, 2026-10-01: "the budgets are a hypothethical control target to ensure we are thinking along a value engineering lens"). Estimated cost of the constructable design: USD 311 for the bike with the helmet that is now supplied with every bike (decided 2026-10-02), BOM lines 1 to 20, USD 11 over the target; USD 299 for the bike alone, lines 1 to 19 (USD 1 under the target). The concept was USD 281 and 293; the parts added for construction account for the USD 18 difference. Frame builder labor is not included.

Main cost drivers:

- Frame tube, plate and consumables, USD 64 (line 1).
- Solid tires, USD 32 for the pair (line 9).
- Rear wheel with coaster hub, USD 30 (line 8).
- Quill stem with its head plate and clamp block, USD 20 (line 5).
- Fork with a long steerer, USD 18 (line 2).

Savings worth trying:

- Thorn-resistant tubes with liners instead of solid tires: about USD 10 and 0.5 kg less, but it reverses D4 (GRR-DDR-001), so it needs Amish's decision.
- A bought steel rack of the right size and rating instead of the welded aluminium one: no aluminium welding skill needed; check mass and price.
- One collar size: a 30.0 mm sleeve would take a stock collar, but the sleeve size was decided (GRR-DDR-002, D10), so only worth revisiting with the strength screen.
- A bought long quill stem cut and fitted with the head plate, if a 22.0 mm chromoly quill of 240 mm is stocked.
- Price the frame kit (tubes, dropouts, BB shell) as one order from a frame-building supplier.

## Decisions made

| Date | Decision | Decided by | Record |
| --- | --- | --- | --- |
| 2026-09-25 | D1 to D6: 20 in (ISO 406) wheels; coaster brake plus front rim brake; step-through frame with twin down tubes; solid or airless tires for the prototype; one 140 mm crank length; USD 120 production cost target at volume | Amish: "proceed with all of your recommendations across all batches. Make sure we don't proceed to TRL 4 on any of them." | GRR-DDR-001 |
| 2026-09-25 | D7 to D13: chromoly main tubes, aluminium rack, alloy rims and bar (R5 kept as the production goal); alloy front rim; obtain the coaster hub brake ratio; chromoly steerer and quill, 1.8 mm sleeve; R2 widened to 400 to 670 mm; R9 split into parent and mechanic tool lists; low bar as a co-design question | Amish: "i accept all your recommendations, go with them across all repos." | GRR-DDR-002 |
| 2026-09-26 | N1: prototype budget raised from USD 250 to USD 300 | Amish: "I am ok with the budget top ups" | GRR-DDR-002 |
| 2026-09-30 | Make the design physically buildable while drawing the build plan; keep open decisions out of the build plan and in this register | Amish: "If you are realising that the design cannot be built as per concept - fix the design assumptions to match and be physically feasible as you draw the illustrations." The changes themselves were accepted on 2026-10-01 (below) | GRR-DDR-003 |
| 2026-10-01 | `budget_usd` is a value-engineering target, not a limit; cost is reported over or under it | Amish: "the budgets are a hypothethical control target to ensure we are thinking along a value engineering lens. its ok to ensure wording reflects that the hypothesis budget was x - the real cost being accrued is y" | This register, Value engineering |
| 2026-10-01 | Design for construction accepted: the changes P1 to P17 and their knock-on changes, as made | Amish: "i agree with your recommendations for both GrowRider and GravitySort" | GRR-DDR-003, Tables 1 and 2 |
| 2026-10-01 | Quill stem: no positive stop for the prototype; the minimum insertion mark, checked at every fit change, with a bright painted band above it. Follow-up: decide on the stop collar of option (b) after the fit trials | Amish: "i agree with your recommendations for both GrowRider and GravitySort" | GRR-DDR-003, A1 |
| 2026-10-01 | Mass of 15.1 kg accepted for the prototype (R5 production goal of 13 kg still not met); the prototype is weighed at TRL 4 | Amish: "i agree with your recommendations for both GrowRider and GravitySort" | GRR-DDR-003, A2 |
| 2026-10-01 | Steerer: keep the 25.4 x 1.6 mm steerer and let the ISO 4210-2 fork test decide | Amish: "i agree with your recommendations for both GrowRider and GravitySort" | GRR-DDR-002, N2; GRR-DDR-003, A3 |
| 2026-10-01 | Renders: 1.30 m rider setting in the product renders, 1.38 m in the concept sheet | Amish: "i agree with your recommendations for both GrowRider and GravitySort" | `docs/REVIEW.md`, 2026-09-26, item 2 |
| 2026-10-01 | Frame color: kit teal for the portfolio renders; the production color is settled in co-design, with a high-visibility option | Amish: "i agree with your recommendations for both GrowRider and GravitySort" | `docs/REVIEW.md`, 2026-09-26, item 3 |
| 2026-10-01 | Painted height scales on the exposed sleeve and quill: a band every 20 mm, a longer band every 60 mm | Amish: "i agree with your recommendations for both GrowRider and GravitySort" | `docs/REVIEW.md`, 2026-09-26, item 4 |
| 2026-10-01 | Markings: the name "GrowRider" screen printed on the chainguard; no head badge | Amish: "i agree with your recommendations for both GrowRider and GravitySort" | `docs/REVIEW.md`, 2026-09-26, item 6 |
| 2026-10-02 | Helmet (BOM line 20): an adjustable, ventilated child helmet is supplied with every bike through the partner program and fitted at handover; its USD 12 stays in the bike's cost, so USD 311 is the prototype figure | Amish: "i approve your recommendations for all 555 open decisions." | GRR-DDR-001, O1 |
| 2026-10-02 | First partner and co-design partner: World Bicycle Relief, through its school bicycle programs and field mechanics, is the first candidate to approach for fit measurements and the regional parts list | Amish: "i approve your recommendations for all 555 open decisions." | GRR-DDR-001, O2 and O4 |
| 2026-10-02 | First region: Zambia is the first candidate region, for checking the regional parts list (items 1 to 12 below) | Amish: "i approve your recommendations for all 555 open decisions." | GRR-DDR-001, O3 |

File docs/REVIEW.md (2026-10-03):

# Review note: GrowRider

## Session 2026-09-24: /populate to a strong TRL 2

### What was done

- `docs/01-problem.md` (GRR-PRB-001 v0.2): problem, users and context (child riders, parents, schools, NGOs and distribution programs, local mechanics), constraints, out of scope, prior work, open questions. The co-design checklist is kept unchanged.
- `docs/03-requirements.md` (GRR-REQ-001 v0.2): 12 measurable requirements (R1 to R12) with targets, planned verification and stated assumptions.
- `docs/02-concept.md` (GRR-PRC-001 v0.2): how it works, 17 numbered components, fit and commute-time numbers with assumptions, braking and power estimates, design choices, safety, open questions.
- `cad/src/concept_media.py`: massing model of a step-through child's bicycle built from tubes (frame, fork, wheels, tires, telescoping seat post shown extended, telescoping stem, handlebar, saddle, crankset, chain line, front brake, rack, fenders, chainguard, kickstand, reflectors). Scale reference: a 1.35 m child (`human_figure(height=1350)`) passed as a context part with `scale_figure=False`, chosen because it shows the fit better than the 1.75 m adult. No cutaway (`cut=False`), since the inside of a bicycle does not add information.
- `media/`: hero, blueprint sheet (PNG and PDF), exploded view with BOM callouts, growth and hand-down flow diagram, `model.glb` and `viewer.html`.
- `bom/bom.csv`: 20 lines with indicative prices; lines 1 to 17 match the exploded view callouts, 18 to 20 are not modeled. `bom/bom-notes.md` explains totals and commonality.
- `README.md`: hero image and links to the viewer, blueprint and this note.
- `docs/pdf/`: branded PDFs of the three controlled documents.

### Key results (estimates, to be checked at TRL 3)

| Quantity | Estimate | Requirement |
| --- | --- | --- |
| Fit range | 1.10 to 1.65 m riders; saddle height 436 to 654 mm | R1, R2 met |
| Standover | about 460 mm with 20 in wheels | R1 met, thin margin (about 510 mm with 24 in, not met) |
| Reach and bar height adjustment | about 124 mm and 113 mm | R3 met; reach need rests on an assumed 0.2 x height |
| Mass | about 15.5 kg | **R5 (13 kg) not met** |
| Coaster brake alone | about 0.27 g dry, 0.19 g on loose gravel | R7 met dry, marginal on gravel; front brake needed |
| School trip, 5 km | 25 to 30 min cycling vs 60 to 75 min walking; 60 to 100 min saved per day | Motivation |
| Prototype parts cost | about $243 for the bike, $255 with helmet | R11 met for the bike; $5 over with the helmet |

Requirements not met or at risk:

- **R5 mass:** about 15.5 kg against 13 kg. Solid tires, twin down tubes, rack and fenders all add weight.
- **R10 parts commonality:** met in intent for wear parts, but tires and rims are not a roadster size with either 20 in or 24 in wheels. Commonality is unverified until a partner supplies a regional parts list.
- **R11 cost:** within budget without the helmet, $5 over with it.
- **R12 lifespan:** unverified. Seizing of the sliding joints in dust is the main risk.

### Proposed, awaiting Amish

1. Wheel size: 20 in (ISO 406), recommended, or 24 in (ISO 507), which fails standover for 1.10 m riders. **Decided by Amish, 2026-09-25: go with recommendation.** (GRR-DDR-001)
2. Brakes: coaster brake plus front rim brake, recommended; alternatives are coaster only or two hand brakes. **Decided by Amish, 2026-09-25: go with recommendation.** (GRR-DDR-001)
3. Frame: step-through with twin down tubes, recommended, or a small diamond frame. **Decided by Amish, 2026-09-25: go with recommendation.** (GRR-DDR-001)
4. Tires: solid or airless, recommended for the prototype, or thorn-resistant tubes with liners (about 1 kg lighter and $10 cheaper). **Decided by Amish, 2026-09-25: go with recommendation.** (GRR-DDR-001)
5. Helmet (still proposed, awaiting Amish; no recommendation): supply one with each bike (BOM line 20). Either fund it from the $250 budget ($5 over), fund it separately, or raise the budget to about $275. The budget in `project.yaml` is unchanged at $250.
6. Crank length: one 140 mm length for the prototype, with a possible 127 mm swap for the smallest riders later. **Decided by Amish, 2026-09-25: go with recommendation.** (GRR-DDR-001)
7. Production cost target of $120 or less at volume (R11): **decided by Amish, 2026-09-25: go with recommendation** (GRR-DDR-001, D6). First partner and region (a distribution NGO or school network, in Zambia, Kenya or Malawi): still proposed, awaiting Amish.

### Safety concerns

- Child riders on shared roads: two independent brakes, reflectors and a bright frame are required, and a light is suggested for dawn and dusk trips.
- Telescoping seat post and stem must never be raised past minimum insertion; marks plus a positive stop are proposed.
- The 10 kg rack rating protects the child. The design must discourage carrying passengers and water, and the documents must not describe it as a cargo or water bike.
- Bike mass is about three quarters of a six-year-old's body weight.
- Nothing has been built or tested. Frame, fork, rack and brakes need tests to ISO 8098 or ISO 4210 before anyone rides it.

### Suggestions (not added to the repo)

- A hub dynamo light as an option for dark commutes.
- A school fit-check card: a simple chart that maps a child's height to seat post and stem marks.

### Recommended next step

Review this note and the media, and decide the proposed items above, especially wheel size and brakes. If approved, run `/advance-trl3` to check the fit geometry, braking, frame loads and mass by calculation, and to produce the parametric model and drawing sheet. In parallel, find a partner for co-design so the anthropometric and parts-commonality assumptions can be tested.

## Session 2026-09-25: TRL 3

Amish's instruction for this session (2026-09-25): "proceed with all of your recommendations across all batches. Make sure we don't proceed to TRL 4 on any of them." GrowRider now claims TRL 3 (proof of concept on paper). TRL 4 is on hold by Amish's instruction.

### What was done

- `docs/decisions/0001-trl2-review-decisions.md` (GRR-DDR-001 v0.1): six TRL 2 review items with a recommendation recorded as decided by Amish, 2026-09-25, and four items that stay open.
- `docs/04-calcs/01-sizing.md` (GRR-CAL-001 v0.1) and `docs/04-calcs/sizing.py`: fit under two saddle-height rules, seat post and quill insertion and bore depth, standover, reach and bar height, trail, crown and fender clearance, toe overlap, pedal clearance, mass from the model's tubes, rider-plus-bike mass center, rack, braking (grip limits, coaster back-pedal force, rim brake lever force dry and wet), service task analysis, BOM total, a strength screen of six sections, drive, power, trip time and the applicable ISO standard. The script imports the model's `PARAMS` and prints every number the note quotes, tagged [A1] to [M1].
- `cad/src/model.py`: parametric build123d model (frame, fork with long steerer, two-stage seat post, saddle, quill stem with two-position head, handlebar, wheels, solid tires, crankset, chain, front brake, rack, fenders, chainguard, kickstand, reflectors) with rider settings. Exports `cad/step/growrider-small.step`, `growrider-large.step`, `frame.step`, `fork.step`, `seat-post-assembly.step`, `stem-and-bar.step`, `rack.step` and matching STL files in `cad/stl/`.
- `cad/src/sheets.py` and `cad/drawings/GRR-DWG-001.svg`, `.pdf`, `.png`: general arrangement at Rev P1, scale 1:10, ortho views at the largest setting with overall length and height, wheelbase, BB height, standover, width and bar width drawn from the model; isometric at the smallest setting; a main-dimensions box. The sheet carries "CONCEPT, NOT FOR FABRICATION" and "PRELIMINARY, NOT FOR FABRICATION". The concept sheet remains GRR-DWG-010, so DWG-001 was free for the general arrangement.
- `bom/bom.csv` and `bom/bom-notes.md`: all 20 lines priced with a supplier type; specs updated to the model.
- `cad/src/concept_media.py` now builds the media from `model.py` (bike set for a 1.38 m rider beside a 1.35 m child), with key figures from GRR-CAL-001. All media in `media/` were regenerated and checked by eye; the temporary `media/_views*` folders were deleted.
- GRR-PRB-001, GRR-PRC-001 and GRR-REQ-001 revised to v0.3 (decisions recorded, numbers replaced by GRR-CAL-001, requirement status column); `README.md` updated to TRL 3 with links; `project.yaml` set to `trl: 3`, `trl_target: 3`, with the evidence files listed. PDFs are in `docs/pdf/`.

### Requirements (GRR-CAL-001, Table 6)

5 met, 1 not met, 4 at risk, 2 not verifiable at TRL 3.

| ID | Status | Value against target |
| --- | --- | --- |
| R5 | **Not met** | 15.3 kg against 13 kg; 81 % of a 19 kg six-year-old. All five saving options together reach about 13.1 kg |
| R7 | At risk | Smallest rider, dry: coaster 0.22 g (85 N back-pedal force needed, about 93 N available), front 0.24 g, both 0.46 g. Wet steel rim about 0.05 g |
| R9 | At risk | Fit change about 10 min with a 13 mm spanner and a screwdriver; headset needs a 32 mm spanner and the BB a lockring spanner |
| R11 | At risk | $243 for the bike, $255 with the helmet (helmet funding open); production cost not estimated |
| R12 | At risk | 3 of 6 sections above the 60 MPa fatigue screen at 1 g: sleeve at the seat tube top 74 MPa, quill at full extension 77 MPa, steerer in hard braking 117 MPa; none above yield. Seizing of sliding joints not assessable |
| R8 | Not verifiable at TRL 3 | Solid tires cannot puncture; tire life needs supplier data |
| R10 | Not verifiable at TRL 3 | Parts chosen to match roadsters; needs a regional parts list |
| R1 | Met | 1.10 to 1.65 m; standover 455 mm against 470 mm (40 mm below the smallest inseam) |
| R2 | Met | Saddle 400 to 670 mm; 100 mm insertion at every sliding joint |
| R3 | Met | Bar height 113 mm; reach 141 mm |
| R4 | Met | 20 in (ISO 406) |
| R6 | Met | 300 x 120 mm platform; 35 MPa at 10 kg and 2.5 g |

Other key numbers: trail 59 mm; fork crown to fender 6 mm; toe overlap up to 19 mm for the largest rider; grips 128 mm above the saddle at the smallest setting; gear 2.79 m per turn (66 rpm at 11 km/h); 34 W on the level and 65 W on a 5 % climb for a 1.38 m rider; about 79 min a day returned on a 5 km trip. The adult fitting rule used at TRL 2 put the smallest saddle 36 mm too high for 140 mm cranks; the design now covers the crank-corrected rule too. Every TRL 2 number in the docs was checked against the script and corrected where it differed (GRR-CAL-001, "Checks against earlier figures").

### Decisions recorded (GRR-DDR-001)

Decided by Amish, 2026-09-25, going with the recommendation: D1 20 in (ISO 406) wheels; D2 coaster brake plus front rim brake; D3 step-through frame with twin down tubes; D4 solid or airless tires for the prototype; D5 one 140 mm crank length for the prototype; D6 production cost target $120 or less at volume. No requirement target was relaxed or redefined; `budget_usd` stays at $250 and the pitch and problem lines are unchanged (no rewording was recommended). The SwapCell decisions do not apply to GrowRider.

D6 was read as carrying a recommendation because the TRL 2 note proposed the $120 figure itself; if Amish did not mean to fix it, it reverts to proposed.

### Proposed, awaiting Amish (items 3 to 9 decided on 2026-09-25, see GRR-DDR-002)

Still open from TRL 2 (no recommendation was made):

1. Helmet funding (O1): from the $250 budget ($5 over), funded separately, or a budget of about $275.
2. First partner (O2) and first region (O3). Per Amish's portfolio instruction, co-design partners are picked per area later (O4).

New from TRL 3:

3. **Mass (R5).** Options: (a) relax R5 to 15.5 kg for the prototype and keep the decided solid tires; (b) adopt chromoly main tubes, an aluminium rack, alloy rims and bar (about 13.6 kg, some added cost), keeping solid tires; (c) all of (b) plus pneumatic tires with liners (about 13.1 kg), which reverses D4. Recommendation: (b), and keep R5 at 13 kg as the production goal. **Decided by Amish, 2026-09-25: go with recommendation.** (GRR-DDR-002)
4. **Alloy front rim (R7).** Specify an alloy front rim, since a wet steel rim gives a child about 0.05 g. Recommendation: adopt; BOM line 7 already prefers alloy at the same price. **Decided by Amish, 2026-09-25: go with recommendation.** (GRR-DDR-002)
5. **Coaster hub data (R7).** Get the brake ratio of a regional coaster hub; the smallest rider's margin rests on an assumed ratio of 2.5. Recommendation: do this before any further brake work. **Decided by Amish, 2026-09-25: go with recommendation.** (GRR-DDR-002)
6. **Strength (R12).** Specify chromoly or thicker-walled sleeve, quill and steerer, or limit the maximum extension. Recommendation: chromoly steerer and quill, and a 1.8 mm wall sleeve; recheck in GRR-CAL-001. **Decided by Amish, 2026-09-25: go with recommendation.** (GRR-DDR-002)
7. **R2 target.** Widen R2 to 400 to 670 mm to match the crank-corrected fit rule the design already meets. Recommendation: adopt. **Decided by Amish, 2026-09-25: go with recommendation.** (GRR-DDR-002)
8. **R9 tools.** Either add a 32 mm headset spanner and a BB lockring spanner to R9 for mechanics, or keep R9 for parents' fit changes only. Recommendation: split R9 into a parent tool list (13 mm spanner, screwdriver) and a mechanic tool list. **Decided by Amish, 2026-09-25: go with recommendation.** (GRR-DDR-002)
9. **Low bar option.** Offer a flat bar for the smallest riders, since the grips sit 128 mm above the saddle at the smallest setting. Recommendation: note as a co-design question. **Decided by Amish, 2026-09-25: go with recommendation.** (GRR-DDR-002)

### Safety concerns

- Child riders on shared roads; nothing built or tested. The applicable standard by saddle height is ISO 4210-2 (city and trekking), whose tests assume adult riders.
- Braking margins for a 1.10 m rider are small on paper, the coaster brake is lost if the chain comes off, and a wet steel rim barely brakes.
- Sliding joints at full extension carry the highest stresses; minimum insertion marks and positive stops are required, and clamp slots are pinch points.
- The bike is about 81 % of a six-year-old's weight; 10 kg on the rack cuts the front wheel load from 40 % to 33 % for the smallest rider.
- Toe overlap for the largest riders; 6 mm fender-to-crown clearance can pack with mud and lock the front wheel.

### Other notes

- No existing TRL 4 material was found (`build-log/` holds only its README; `electronics/` and `firmware/` are empty). None was created. STANDARDS section 9 asks for a TRL change to be recorded in the build log; no build-log entry was written, since the brief did not name one.
- Citations: no unchecked citations were listed at TRL 2. The ISO 8098 and ISO 4210-2 saddle height scopes quoted in GRR-CAL-001 and GRR-PRB-001 were checked on the ISO catalog pages; the standards' test loads were not read. BOM prices are indicative estimates by supplier type, not quotes. Rider masses, lever and back-pedal forces, the coaster brake ratio and catalog part masses are assumptions stated in GRR-CAL-001, Table 1.

### Recommended next step

Stay at TRL 3. TRL 4 is on hold by Amish's instruction. Decide items 3 to 8 above, starting with mass and the alloy rim, get coaster hub brake data and catalog masses for the tires, rims and hub, then revise GRR-CAL-001, the model and the BOM on paper. In parallel, a co-design partner is needed to test the fit assumptions and supply a regional parts list.

For reference only, TRL 4 would need: a lab test report (TST, `environment: lab`) on a built frame, fork and seat post (ISO 4210-2 frame and fork fatigue and impact, seat post and stem tests, brake performance with child-level forces, rack static load), weighing, a timed fit change, build-log entries, and the purchasing and build work that goes with them. None of this has been started.

## Session 2026-09-25: recommendations accepted

Amish wrote on 2026-09-25: "i accept all your recommendations, go with them across all repos." Every item above with a recommendation is now **Decided by Amish, 2026-09-25: go with recommendation**, recorded in `docs/decisions/0002-recommendations-accepted.md` (GRR-DDR-002 v0.1). Items without a recommendation stay proposed. `trl` and `trl_target` stay at 3.

### Decisions applied and what changed

| # | Decision | Change in the repo | Before | After |
| --- | --- | --- | --- | --- |
| D1 to D6 | Wheel, brakes, frame, tires, crank, $120 production target (GRR-DDR-001) | Confirmed; no further change | | |
| D7 | Mass option (b): chromoly main tubes, aluminium rack, alloy rims and bar; solid tires kept; R5 kept at 13 kg as the production goal | `model.py` walls and rack; BOM lines 1, 6, 8, 13; R5 restated | 15.3 kg | 14.4 kg (the TRL 3 note had estimated 13.6 kg) |
| D8 | Alloy front rim | BOM line 7; R7 text | Wet front braking, smallest rider, 0.05 g (steel) | 0.15 g (alloy) |
| D9 | Get the coaster hub brake ratio first | Open action; needs hub maker or partner data. Any purchase or bench test is TRL 4, on hold | Assumed ratio 2.5 | Unchanged until data arrives |
| D10 | Chromoly steerer and quill, 1.8 mm sleeve wall | Sleeve 28.6 x 1.5 to 29.2 x 1.8 mm chromoly; seat tube 1.5 to 1.2 mm wall for a 29.4 mm bore; chromoly screen 90 MPa added to GRR-CAL-001 | 3 of 6 sections above screen (sleeve 74, quill 77, steerer 117 MPa) | 1 of 6 (steerer 117 MPa against 90 MPa); sleeve 61, quill 77, seat tube 72 MPa pass |
| D11 | Widen R2 | GRR-REQ-001 | 436 to 654 mm | 400 to 670 mm (met) |
| D12 | Split R9 | GRR-REQ-001 (R9a parent, R9b mechanic) | Tools at risk | Both tool lists met; 10 min fit change at the limit |
| D13 | Low bar as a co-design question | GRR-PRB-001 and GRR-PRC-001 open questions | | |

Cost: the BOM rose from $243 to $281 for the bike and from $255 to $293 with the helmet (+$38: frame +$18, steerer, sleeve and quill +$12, bar and rear rim +$4, rack +$4). `budget_usd` stays at $250, since no budget recommendation existed; a change is proposed below.

Files changed: `cad/src/model.py` (and STEP and STL re-exported), `cad/src/sheets.py` and GRR-DWG-001 at Rev P2, `cad/src/concept_media.py` and all of `media/`, `docs/04-calcs/sizing.py`, GRR-CAL-001 v0.2, GRR-REQ-001 v0.4, GRR-PRC-001 v0.4, GRR-PRB-001 v0.4, `bom/bom.csv`, `bom/bom-notes.md`, `project.yaml` (evidence list), `README.md`, and GRR-DDR-002 v0.1 (new). The README gained the sections Concept rationale, Burning platform, Where it could be used and What sparked the idea; the inspiration point is the Bihar Chief Minister's Bicycle program (2006) and its evaluation by Muralidharan and Prakash (2017). All PDFs, drawings and media were regenerated so none shows the old domain.

### Requirement status (GRR-CAL-001 v0.2)

5 met, 2 not met, 3 at risk, 2 not verifiable at TRL 3 (was 5, 1, 4, 2).

| ID | Status | Value against target |
| --- | --- | --- |
| R5 | **Not met** | 14.4 kg against the 13 kg production goal (was 15.3 kg); pneumatic tires would reach about 13.9 kg but reverse D4 |
| R11 | **Not met** | $281 bike, $293 with helmet, against $250 (was $243 and $255, at risk) |
| R7 | At risk | Smallest rider, dry: coaster 0.23 g, front 0.24 g, both 0.47 g; hub ratio still assumed |
| R9 | At risk | Tool lists met; fit change 10 min, at the limit |
| R12 | At risk | Steerer 117 MPa against the 90 MPa chromoly screen; seizing not assessable |
| R8 | Not verifiable at TRL 3 | Tire life needs supplier data |
| R10 | Not verifiable at TRL 3 | Needs a regional parts list |
| R1, R2, R3, R4, R6 | Met | Standover 455 mm; saddle 400 to 670 mm; bar 113 mm and reach 141 mm; 20 in; rack 26 MPa in aluminium |

### Still awaiting Amish

1. O1 Helmet funding (no recommendation).
2. O2 First partner and O4 co-design partner (picked per area later).
3. O3 First region (no recommendation).
4. ~~N1 (new) Prototype budget~~ **Decided by Amish, 2026-09-26: budget top-up to $300** (see the session below).
5. N2 (new) Steerer: specify a 25.4 x 2.0 mm butted chromoly steerer (98 MPa, still above the screen) and confirm by the ISO 4210-2 fork tests. Recommendation: adopt, and accept that the fork test decides.

### Cross-repo actions

None. No decision for GrowRider needs another repo to change.

### Safety

- The aluminium rack is new: welded aluminium has low fatigue strength, so the rack needs static and fatigue tests before any use.
- The thinner chromoly tubes depend on competent brazing or TIG welding; a local builder used to hi-tensile steel may not have it.
- Wet braking with the alloy rim (about 0.15 g for the smallest rider) is still well below dry braking.
- Nothing has been built or tested; nothing may be ridden.

### TRL 4

TRL 4 remains on hold by Amish's instruction. D9 (hub data) and the tests named above are recorded but not started; no build, test, purchasing or build-log work was done.

## Session 2026-09-26: sources strengthened

Amish asked on 2026-09-26 to fix the weaker sources and approved the budget top-up ("I am ok with the budget top ups").

### Sources

Three rows of "By country or region" in `README.md` had no citation. Each was rewritten to state only what a verified source supports:

| Row | Old source | New source |
| --- | --- | --- |
| Andean and rural Latin America (Peru, Bolivia) | None | Replaced by Latin America (Bogotá, Colombia): [Alcaldía de Bogotá](https://bogota.gov.co/mi-ciudad/educacion/movilidad-en-bogota-al-colegio-en-bici-beneficios-para-estudiantes), Al Colegio en Bici and the city's other guided school-travel programs, more than 9,000 students from 147 public schools (2024) |
| Southeast Asia (Cambodia, Myanmar) | None | Narrowed to Cambodia: [Agence Kampuchea Presse](https://www.akp.gov.kh/post/detail/374647), 200 donated bicycles for pupils of five schools in Banteay Meanchey province who had walked several kilometres a day (July 2026) |
| Netherlands and other high-income cycling countries | None | [Veldman, Westerbroek and Singh, *Transportation Research Interdisciplinary Perspectives*, 2026](https://doi.org/10.1016/j.trip.2026.101998): 64 % of Dutch primary school children in the study cycled to school at least once a week. The claim "children ride to school daily" was dropped |

The other sources (UNESCO, WHO, Muralidharan and Prakash in the *American Economic Journal: Applied Economics*, NBER) are primary and were kept. The inspiration (Bihar Chief Minister's Bicycle program and its peer-reviewed evaluation) already rests on primary sources and is unchanged.

### Budget

- `project.yaml`: `budget_usd` 250 to 300.
- `docs/04-calcs/sizing.py` now reads the budget from `project.yaml` and was re-run: [J1] $281 bike, $293 with helmet, against $300; R11 moves from not met to at risk (prototype within budget; the $120 production target is not yet estimated). Totals: 5 met, 1 not met, 4 at risk, 2 not verifiable.
- GRR-CAL-001 v0.3, GRR-REQ-001 v0.5, GRR-PRC-001 v0.5 and GRR-PRB-001 v0.5 record the new budget and R11 status; GRR-DDR-002 v0.2 records "Budget top-up to $300: decided by Amish, 2026-09-26" against N1 and notes that the $293 total with the helmet now fits (O1's funding question).
- `README.md`: budget badge line and cost sentences updated to $300.

## Session 2026-09-26: product appearance model and photoreal renders

Amish chose this repo on 2026-09-26 for the first batch of product renders. This session adds an appearance model for photoreal renders; it does not change the design, the calculations or the BOM.

### What was done

- `cad/src/product_model.py` (new): `product_parts()` returns 75 parts (74 bike parts in the "shell" and "internal" groups and one "context" part), with `TITLE` and three `RENDER_VIEWS`: "hero" (front right, about 22 deg elevation, with the rider), "exploded" (front right, about 28 deg) and "detail" (bike alone, front right, about 14 deg, framing the adjustable frame). Every main dimension and interface comes from `PARAMS`, `derived()` and the point helpers in `cad/src/model.py`, which is unchanged.
- The appearance model adds:
  - a painted frame (kit accent #0F766E) with rear dropouts, a kickstand plate and a head badge;
  - the two-stage seat post (graphite sleeve, chrome post) and the chrome quill with split clamp collars, 13 mm bolts and painted height scales on the exposed sleeve and quill;
  - a shaped vinyl saddle with base, rails and clamp;
  - alloy rims with brake tracks, laced spokes (28 front, 36 rear, as in the BOM) with nipples, hubs, axle nuts and the coaster brake arm; solid tires with a cut tread;
  - a toothed 32T chainring and 18T sprocket, an 86-link chain, shaped cranks, platform pedals with reflectors;
  - a side-pull caliper with pads, the short-reach lever and a cable housing;
  - the aluminium rack with a raised "MAX 10 kg" rating plate, fenders with side lips, stays and a mud flap, the chainguard with the name raised on it, kickstand, reflectors and bell;
  - a clay mannequin of a 1.30 m child (about age 8), group "context", riding the bike set for that height (saddle 505 mm from the BB, stem raised 45 mm), fitted so the seat meets the saddle, the hands meet the grips and the feet meet the pedals.
- `README.md`: the hero image now points to `media/render-hero.png`, and the links line starts with the exploded render. The render files are produced later by the orchestrator.
- Self-check previews (matplotlib, not committed): `/tmp/growrider-prod/prev-hero.png`, `prev-exploded.png`, `prev-detail.png`.

### Differences from model.py (appearance only)

1. Spoke count: the massing model draws 18 spokes per wheel; the appearance model uses the BOM counts (28 front, 36 rear). No decision needed.
2. Rider setting shown: the renders show the bike set for a 1.30 m rider; the concept media show 1.38 m. Proposed, awaiting Amish. Recommendation: keep 1.30 m for the product renders (the child mannequin reads as a younger rider) and 1.38 m for the concept sheet.
3. Frame colour: kit accent teal (#0F766E) instead of the blue (#2E5E8C) of the concept media. The precis proposes a bright frame for road visibility. Proposed, awaiting Amish. Recommendation: use teal for the portfolio renders and settle the production colour in co-design, with a high-visibility option.
4. Painted height scales on the exposed sleeve and quill (a band every 20 mm, a longer band every 60 mm): not in the model or the BOM. Proposed, awaiting Amish. Recommendation: adopt; a teacher or mechanic can note a child's setting and reset it quickly, which helps the at-risk fit-change time.
5. Rear dropouts drawn as rear-facing track ends for chain tension on the single-speed coaster hub; the massing model has plain blocks. Proposed, awaiting Amish. Recommendation: adopt, as on regional roadsters.
6. Markings: the name "GrowRider" on the chainguard and a head badge are not in the BOM. Proposed, awaiting Amish (naming and branding are his decision). Recommendation: keep the chainguard name, which costs nothing if screen printed.
7. Small placements: the brake lever sits in front of the right grip (the massing model's lever line runs back from the grip), the pedal bodies sit about 8 mm further out, and the chainguard gains a rolled top edge. No decision needed.
8. The mannequin's feet sit at hip width, so they rest on the inner half of the pedals. A render limitation only.

### TRL

This is an appearance model only: no tolerances, no fabrication detail and nothing past TRL 3. `trl` stays 3 in `project.yaml`, and TRL 4 remains on hold by Amish's instruction.

## Session 2026-09-27: kit 1.5.0 and image quality

- Kit 1.5.0 synced: STANDARDS v1.5 (sections 12 to 15: product renders, storefront images and image quality, public release, authorship and signing), `.kit/cards.py`, `.kit/image_qc.py`, `.kit/release_gate.py`, issue templates, and the `/render-product` and `/release` commands. `CLAUDE.md` now matches `.kit/CLAUDE.md`.
- Every `media/render-*.png` recaptioned from its original render with the new layout: the title, concept label and repository sit in a band above the render and the view note in a band below it, each line wrapped to the image width, so no text overlaps other text or the render or runs off the image. `media/card.png` and `media/social-preview.png` regenerated with the same rules.
- `python .kit/image_qc.py` and `python .kit/release_gate.py` pass. trl stays 3.

## Session 2026-10-01: constructable design and prototype build plan (kit 1.7.0)

Amish approved the build plan format on 2026-09-30 and asked for it on every repo, with the instruction "If you are realising that the design cannot be built as per concept - fix the design assumptions to match and be physically feasible as you draw the illustrations", and with open decisions kept out of the build plan. On 2026-10-01 he set `budget_usd` as a value-engineering target, not a limit. This session brings GrowRider to that standard. trl stays 3.

### What was done

- Kit 1.7.0 installed (`.kit/`, `.claude/commands/`); `CLAUDE.md` matches `.kit/CLAUDE.md`.
- `cad/src/model.py` rebuilt as a constructable design: `build_components()` returns 41 made and bought components; `build_parts()` still groups them into the 17 modelled BOM lines for the concept media; `check()` runs 66 constructability checks with build123d (fits, stop positions, contacts, clearances); all pass (`python cad/src/model.py --check`). STEP and STL regenerated.
- `docs/decisions/0003-design-for-construction.md` (GRR-DDR-003 v0.1, Draft): 17 changes, made under Amish's 2026-09-30 instruction to make the design physically buildable; open for his review; three items proposed, awaiting Amish.
- `docs/05-build-plan.md` (GRR-BLD-001 v0.1) with `cad/src/build_plan_media.py`: overview, frame jig layout, 8 making sketches (GRR-DWG-101 to 108), 9 joint close-ups and 17 assembly step pictures in `docs/05-build-plan/`.
- `docs/06-design-decisions.md` (GRR-DEC-001 v0.1): 11 open decisions, 12 items to confirm when parts are bought, a Value engineering section and the decisions made.
- `bom/bom.csv` lines 1, 2, 3, 5, 6, 12, 14, 16 and 19 respecified; `bom/bom-notes.md` updated.
- `docs/04-calcs/sizing.py` re-run with the new model; GRR-CAL-001 v0.4, GRR-PRC-001 v0.6 and GRR-REQ-001 v0.6 updated; cost stated against the value-engineering target throughout.
- GRR-DWG-001 at Rev P4; concept media (`media/hero.png`, `exploded.png`, `flow.png`, `concept-blueprint.*`, `model.glb`, `viewer.html`) regenerated from the model.
- `project.yaml`: `design_state: constructable`; GRR-DDR-003, the build plan and the register added to `trl_evidence`; `budget_usd` unchanged at 300. README: build plan and register links, "Building the prototype" section with the overview picture.

### Design changes made for construction (GRR-DDR-003)

| # | Change |
| --- | --- |
| P1 | Rear dropouts: 6 mm track-end plates, slot open to the rear, 110 mm apart, M5 eyelets (were plain blocks 105 mm apart) |
| P2 | Fork specified with slotted fork ends 100 mm apart and eyelets (blades ended at the axle) |
| P3 | Coaster brake arm held under the left chainstay by an arm clip and M6 bolt (it floated) |
| P4 | Head tube 34 x 2.0 mm, 30.0 mm bore for 1 in press-in cups (was 31.0 mm) |
| P5 | Quill 22.0 x 2.0 mm so it slides in the 22.2 mm steerer bore (22.2 mm could not) |
| P6 | Stem head: welded 10 mm chromoly head plate and a bolt-on two-piece aluminium bar clamp block at 45 or 105 mm ahead of the axis; bar sweep 205 mm, rise 15 mm; quill lowest exposure 20 mm; grips within 2 mm of the concept |
| P7 | Seat stays join a cross bar 235 mm up, clear of the seat tube collar (were at 260 mm, inside it) |
| P8 | Positive stops: M5 stop screws in both clamp collars riding in side slots in the sleeve and post; 100 mm insertion at the stops |
| P9 | Rack fixed by tabs to the dropout eyelets and to brazed bosses on the seat stays (ends floated) |
| P10 | Seat stays 80 mm apart at the cross bar so the 64 mm rear fender passes; rear fender starts 10 deg above the axle line; fender bridge and wire stays |
| P11 | Rack lowered from 575 to 545 mm so the saddle clears it at the lowest setting |
| P12 | Kickstand plate under the chainstays with a centre-mount kickstand |
| P13 | Fork crown 16 mm deep and front fender 12 mm off the tire; the crown clearance in GRR-CAL-001 was corrected from 26 to 22 mm |
| P14 | Long-reach side-pull caliper (about 84 mm), fender bracket on the same crown bolt |
| P15 | Down tube 5 mm higher on the head tube, clear of the lower cup |
| P16 | Chain line 42 mm (was 48) and chainstays 21 mm each side at the BB; sprocket, chainring and chain clear the frame |
| P17 | Chainguard mounted by a seat tube clip and a chainstay boss |

### Key results

- Mass 15.1 kg (was 14.4 kg); **R5 (13 kg production goal) not met**.
- Value-engineering target: USD 300. Estimated cost of the constructable design: USD 299 for the bike (USD 1 under the target) and USD 311 with the helmet (USD 11 over).
- Smallest rider's coaster braking 0.22 g (was 0.23 g), back-pedal margin 9 %; R7 still at risk.
- Requirement statuses unchanged: 1 not met, 4 at risk, 2 not verifiable at TRL 3, 5 met.

### Proposed, awaiting Amish

All in GRR-DEC-001: accept GRR-DDR-003 (item 1); quill positive stop (item 2, recommendation: insertion mark only for the prototype); 0.7 kg mass increase (item 3, accept); steerer strength now interacting with the quill bore (item 4, let the fork test decide); and the earlier open items (helmet, partner, region, render setting, frame color, height scales, markings).

### Safety

- The quill has no positive stop; its minimum insertion mark is its only limit (safety stop S4 in the build plan). This departs from the concept's safety section and is item 2 in the register.
- Brazed chromoly and welded aluminium need a trained builder; the build plan's safety stops S1 to S7 apply. Nobody may ride the prototype before the ISO 4210-2 tests.

### Stale media

The appearance model was rebuilt on 2026-10-02 (see "Approved follow-ups carried out"). The photoreal renders (`media/render-*.png`), `media/card.png` and `media/social-preview.png` are made on Amish's Mac next and are not in this working copy.

### Recommended next step

Amish reviews GRR-DDR-003 and the register. TRL 4 (building and testing to GRR-BLD-001) remains on hold by his instruction.

## Session 2026-10-01: recommendations accepted

Amish, 2026-10-01: "i agree with your recommendations for both GrowRider and GravitySort". This answers the recommendations in the design decisions register (GRR-DEC-001 v0.1), including GRR-DDR-003. Items whose recommendation was "None made" or "None yet" were not decided and stay open. trl stays 3; no build or test work was done.

### Accepted, as recommended

| Register item (v0.1) | Decision |
| --- | --- |
| 1 | GRR-DDR-003 accepted: design-for-construction changes P1 to P17 and their knock-on changes |
| 2 | Quill stem: minimum insertion mark with a bright painted band above it for the prototype; the stop collar of option (b) to be decided after the fit trials |
| 3 | 15.1 kg accepted for the prototype; weigh it at TRL 4 (R5 still not met against the 13 kg production goal) |
| 4 | Keep the 25.4 x 1.6 mm steerer; the ISO 4210-2 fork test decides |
| 8 | Renders: 1.30 m rider in the product renders, 1.38 m in the concept sheet |
| 9 | Frame color: kit teal for portfolio renders; production color in co-design, with a high-visibility option |
| 10 | Painted height scales on the exposed sleeve and quill (a band every 20 mm, a longer band every 60 mm) |
| 11 | "GrowRider" screen printed on the chainguard; no head badge |

### What changed

- `docs/06-design-decisions.md` (GRR-DEC-001 v0.2): the eight items moved to Decisions made, dated 2026-10-01, with Amish's words and the record; open items renumbered 1 to 3.
- `docs/decisions/0003-design-for-construction.md` (GRR-DDR-003 v0.2, status Draft as for the pilot repos): status line now "accepted" with Amish's words; Table 3 marked as accepted as recommended; a consequence added for A1 to A3.
- `docs/05-build-plan.md` (GRR-BLD-001 v0.2): section 2 says GRR-DDR-003 is accepted; height scale painting added to the sleeve (section 3.3, step 6) and the quill (section 3.6, step 7), with the bright band above the quill's insertion mark; the joint text of section 3.6 and safety stop S4 refer to the band; the chainguard (section 3.9, bought components) carries the screen-printed name. No open decisions were added.
- `docs/02-concept.md` (GRR-PRC-001 v0.7): summary says GRR-DDR-003 is accepted; the safety section states the quill's limit for the prototype (insertion mark with a bright painted band, stop collar to be considered after the fit trials) and the height scales, and the frame color as decided.
- `bom/bom-notes.md`: GRR-DDR-003 noted as accepted.
- PDFs regenerated for GRR-DEC-001 v0.2, GRR-DDR-003 v0.2, GRR-BLD-001 v0.2 and GRR-PRC-001 v0.7; the superseded PDFs removed.

Requirement status is unchanged: 1 not met (R5), 4 at risk (R7, R9, R11, R12), 2 not verifiable at TRL 3, 5 met. No price change: paint and screen printing are within the frame and chainguard lines.

### Still open (GRR-DEC-001)

1. Helmet supply (no recommendation; a co-design question).
2. First partner and co-design partner.
3. First region.

The 12 items to confirm when parts are bought are unchanged.

### Safety

The quill still has no positive stop. For the prototype its limit is the minimum insertion mark, now with a bright painted band above it, checked at every stem setting (safety stop S4). This departs from the concept's original promise of a positive stop on every sliding part, and Amish has accepted it for the prototype; the stop collar is to be revisited after the fit trials.

### Recommended next step

Regenerate the photoreal renders on Amish's Mac (the constructable stem head, dropouts and fittings, at the decided 1.30 m setting, in teal with the height scales and chainguard name). TRL 4 remains on hold by Amish's instruction.

## Session 2026-10-02: open decisions decided

Amish, 2026-10-02: "i approve your recommendations for all 555 open decisions." This approves the recommendation written for each open decision in the design decisions register (GRR-DEC-001 v0.2). trl stays 3; no build or test work was done, and the model, BOM quantities and prices, and pictures are unchanged.

### Decisions recorded

Three decisions, all moved to Decisions made in GRR-DEC-001, dated 2026-10-02:

1. Helmet: an adjustable, ventilated child helmet is supplied with every bike through the partner program and fitted at handover; its USD 12 stays in the bike's cost, so USD 311 is the prototype figure (USD 11 over the USD 300 value-engineering target).
2. First partner and co-design partner: World Bicycle Relief, through its school bicycle programs and field mechanics, is the first candidate to approach.
3. First region: Zambia is the first candidate region.

### Documents changed

- `docs/06-design-decisions.md` (GRR-DEC-001 v0.3): open decisions moved to Decisions made; Value engineering reports USD 311 with the helmet as the prototype figure; confirm item 12 names Zambia.
- `docs/decisions/0001-trl2-review-decisions.md` (GRR-DDR-001 v0.2): O1 to O4 recorded as decided.
- `docs/decisions/0002-recommendations-accepted.md` (GRR-DDR-002 v0.3): O1 to O4 recorded as decided; status line updated.
- `docs/02-concept.md` (GRR-PRC-001 v0.8): helmet safety note, cost row and the parts-stock open question.
- `docs/01-problem.md` (GRR-PRB-001 v0.7): partner and region open questions answered.
- `docs/03-requirements.md` (GRR-REQ-001 v0.7): R11 status reports USD 311 with the helmet (still at risk).
- `README.md`, `bom/bom-notes.md` and the note text of `bom/bom.csv` line 20 (no quantity or price change).

### Follow-up actions to carry approved decisions into the design

1. Decision 1 (calculations): state USD 311 with the helmet as the prototype figure in GRR-CAL-001 (R11 row and the value-engineering paragraph) the next time `docs/04-calcs/sizing.py` is run.
2. Decisions 2 and 3 (docs): approach World Bicycle Relief in Zambia for the regional parts list and fit measurements, then close the twelve items to confirm when parts are bought.

### Points found in the review

- The helmet line (USD 12) was excluded from the bike's USD 299 estimate while the value engineering section also quoted USD 311 with it; with decision 1 accepted, USD 311 is now reported as the prototype figure.

## Approved follow-ups carried out (2026-10-02)

Amish approved all follow-up actions from the open-decision sign-off on 2026-10-02. Results for GrowRider:

1. Decision 1, calculations: done. `docs/04-calcs/sizing.py` now states the cost in the approved wording and leads with USD 311 with the helmet supplied with every bike as the prototype figure; R11 row and the cost paragraph of GRR-CAL-001 (now v0.5) match. Value-engineering target: USD 300. Estimated cost of the constructable design: USD 311 (USD 11 over the target); the bike alone is USD 299. No figure changed and R11 stays at risk. `budget_usd` is unchanged. README headline cost now USD 311.
2. Decisions 2 and 3, World Bicycle Relief in Zambia: not done, outreach by Amish.
3. Appearance model (carried from the stale-media note): done. `cad/src/product_model.py` now takes the frame (6 mm track-end dropouts, cross bar, fender bridge, rack bosses, kickstand plate), the welded head plate with two-piece bar clamp block and bolts, the centre-mount kickstand with its bolt and the chainguard tab and clip straight from `cad/src/model.py`, and the rider setting uses the 45 mm stem head position. Render scenes exported to `/home/claude/renders/growrider`; the photoreal renders, card and social preview are made on Amish's Mac.

Model, BOM, mass and drawings are unchanged, so the general arrangement, concept media and build plan pictures were not regenerated. No requirement status changed.

### Cross-repo actions

None.

### Documents changed

`docs/04-calcs/01-sizing.md` GRR-CAL-001 v0.5; `docs/04-calcs/sizing.py`; `cad/src/product_model.py`; `README.md`; this review note.

## 2026-10-02: photoreal renders redone on the constructable design

Rendered with Blender Cycles on Amish's Mac from the updated appearance model; captioned with `.kit/photo_caption.py`; `media/card.png` and `media/social-preview.png` regenerated with `.kit/cards.py`. Views: hero, exploded, detail. image_qc passes. Appearance deviations are those logged above as proposed, awaiting Amish.

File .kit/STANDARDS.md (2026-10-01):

---
doc_id: OHP-STD-001
title: Documentation and drawing standard
project: Open Hardware Portfolio
doc_type: Standard
version: "1.7"
status: Released
date: 2026-09-30
author: Amish Chadha
license: CC-BY-SA-4.0
revisions:
  - version: "1.0"
    date: 2026-09-24
    author: Amish Chadha
    change: First release of the standard
  - version: "1.1"
    date: 2026-09-24
    author: Amish Chadha
    change: Adopt Technology Readiness Levels (section 9) for project maturity
  - version: "1.2"
    date: 2026-09-24
    author: Amish Chadha
    change: Portfolio phase cap (section 10), concept media standard (section 11), CLAUDE.md guardrails
  - version: "1.3"
    date: 2026-09-24
    author: Amish Chadha
    change: Scale figure, interactive 3D viewer and flow diagrams added to concept media; session slash commands
  - version: "1.4"
    date: 2026-09-26
    author: Amish Chadha
    change: Every sheet and render names the project and its GitHub repository; overall dimensions, ISO centre lines and 300 dpi PNG on sheets; titles name the device and view labels state the viewing direction; optional photoreal renders with Blender
  - version: "1.5"
    date: 2026-09-27
    author: Amish Chadha
    change: Product renders (section 12), storefront images and image quality check (section 13), public release and release gate (section 14), authorship, citation and commit signing (section 15)
  - version: "1.6"
    date: 2026-09-29
    author: Amish Chadha
    change: Licensing metadata with REUSE (section 16), Zenodo DOI and Software Heritage archiving (section 17), release gate checks REUSE and a single CITATION.cff license, archive.py
  - version: "1.7"
    date: 2026-09-30
    author: Amish Chadha
    change: Concept and constructable design states; design decisions register (DEC) kept apart from the build plan; prototype build plan (BLD, section 18) with pictures by component is required TRL 3 evidence; every repo targets TRL 3 during the populate phase; build_views.py; /to-trl3 and /build-plan commands
---

# Documentation and drawing standard

Every project in the portfolio uses this standard, so that each precis, write-up and sketch looks the same and carries its own version history. The standard ships as a kit in each repo's `.kit/` folder. The kit version is in `.kit/KIT_VERSION`.

## 1. Document types and IDs

Every controlled document has a unique ID in the form `PRJ-TYP-NNN`.

- `PRJ` is the three-letter project code listed in section 7.
- `TYP` is the document type code from the table below.
- `NNN` is a sequence number within that project and type, starting at 001.

| Code | Type | Typical file |
| --- | --- | --- |
| PRC | Design precis | `docs/02-concept.md` |
| PRB | Problem statement | `docs/01-problem.md` |
| REQ | Requirements | `docs/03-requirements.md` |
| CAL | Calculation or sizing note | `docs/04-calcs/*.md` |
| DDR | Design decision record | `docs/decisions/*.md` |
| BOM | Bill of materials | `bom/bom.csv` |
| DWG | Drawing or sketch sheet | `cad/drawings/*.svg` |
| BLD | Prototype build plan (section 18) | `docs/05-build-plan.md` |
| DEC | Design decisions register (section 18) | `docs/06-design-decisions.md` |
| TST | Test plan or test report (front matter adds `environment: lab` or `relevant`) | `docs/05-tests/*.md` |

Example: `TBK-PRC-001` is the ThermaBrick design precis.

## 2. Revision scheme

| Artifact | While in draft | When released | Change after release |
| --- | --- | --- | --- |
| Documents | 0.1, 0.2, 0.3 ... | 1.0 | 1.1 for minor edits, 2.0 for a design change |
| Drawings | Rev P1, P2 ... (preliminary) | Rev A | Rev B, C ... |

- Every change to a controlled document adds a row to its revision history before the commit.
- The `version` field in front matter always equals the newest row in `revisions`. The renderer rejects a document where they differ.
- Status is one of `Draft`, `In review`, `Released` or `Superseded`. Draft and In review documents print with a status band on every page.
- Every release is tagged in Git as `<doc_id>/v<version>`, for example `TBK-PRC-001/v1.0`. Drawings are tagged `TBK-DWG-001/revA`.
- Git history is the full audit trail. The in-document revision table is the human-readable summary.

## 3. Document front matter

Every Markdown document under version control starts with this block:

```yaml
---
doc_id: TBK-PRC-001
title: ThermaBrick design precis
project: ThermaBrick
doc_type: Precis
version: "0.1"
status: Draft
date: 2026-09-24
author: Amish Chadha
license: CERN-OHL-S-2.0
revisions:
  - version: "0.1"
    date: 2026-09-24
    author: Amish Chadha
    change: Initial draft
---
```

Quote version numbers so YAML keeps `1.0` as text instead of turning it into a number. List revisions newest last.

## 4. Writing style

- Chicago Manual of Style.
- No em dashes. Restructure the sentence instead.
- Lead each section with its conclusion, then support it.
- SI units throughout, in the form `12 kW`, `450 °C`, `3.2 m`. Imperial values may follow in parentheses.
- Number every figure and table ("Figure 2", "Table 1") and give each a caption.
- State every assumption in the calculation that depends on it.
- Put safety notes in a blockquote starting with **Safety:**.

## 5. Visual identity

| Element | Specification |
| --- | --- |
| Typeface | IBM Plex Sans for text, IBM Plex Mono for code and values (SIL Open Font License, bundled in `.kit/fonts`) |
| Ink | `#111827` |
| Secondary text | `#4B5563` |
| Rules and grid | `#D1D5DB` |
| Accent (one only) | `#0F766E` teal |
| Document page | US Letter, 20 mm margins |
| Drawing sheet | ANSI B landscape (431.8 x 279.4 mm) |
| Footer | Document ID, version, status, license and designmolecule.com on every page |

## 6. Drawing and sketch conventions

- Units are millimeters unless the title block says otherwise.
- Third-angle projection, marked with the symbol in the title block.
- Line weights: visible outlines 0.5 mm, hidden lines 0.25 mm dashed, center lines 0.18 mm chain.
- The title block contains the project, title, drawing number, revision, scale, units, projection, sheet, author, date, material or notes, and license.
- Every sheet and every render names the project and its GitHub repository (from `repo:` in `project.yaml`), at the top of the sheet and in the title block, so a printed or forwarded sheet is never anonymous.
- The drawing title names the device, not only the drawing type (for example "Handheld near-infrared resin scanner: general arrangement").
- Every view label states its scale and viewing direction (for example "Scale 1:1; side elevation looking along +Y"), and every isometric or render states where it is seen from.
- Orthographic views generated with `add_ortho` carry overall dimensions (length and depth on the top view, height on the front view) and ISO 128 centre lines on cylinders; hidden lines are dashed. Tolerances are not shown before TRL 4.
- Sheets are exported as SVG, PDF and a 300 dpi PNG.
- The revision table in the top right of the sheet lists every revision.
- Concept sketches use the same sheet and title block and carry the label "CONCEPT, NOT FOR FABRICATION".
- Geometry comes from `cad/src/*.py` (build123d). Sheets are generated by `.kit/drawing.py` and never edited by hand.

## 7. Project codes

| Code | Project | Code | Project | Code | Project |
| --- | --- | --- | --- | --- | --- |
| TBK | ThermaBrick | PCF | PicoFlow | HLT | HelioLite |
| CCB | CharCube | DRN | DustRunner | TRT | TremorTrace |
| STC | StepCue | FXH | FlexHand | CPD | ColdPod |
| SCL | SunClave | STR | SteamRoot | GGD | GrainGuard |
| SDL | SeedLine | ZBX | ZeerBox | RMS | RootMesh |
| DWD | DewDrive | SSK | StillStack | PPR | PotPress |
| WWT | WaterWatch | LMF | LumaFlow | FCL | FieldCell |
| CNP | ConePro | CVC | CulvertCrawl | EGD | EmberGuard |
| SNF | SnapFrame | CGM | CargoMule | SCM | StepClimber |
| SWC | SwapCell | PLP | PalletPilot | FTK | FlatTrike |
| WWK | WaterWalker | GRR | GrowRider | SSP | SunSpoke |
| SGN | StepGen | PBX | PowerBox | WML | WasteWise-ml |
| WSC | WasteWise Scan | RFE | ReflowEconomy | | |
| OHP | Portfolio-wide | | | | |

## 8. Build and publish

- `python .kit/render.py` checks every controlled document and renders it to `docs/pdf/<doc_id>_v<version>.pdf`.
- `python .kit/drawing.py` (called from each project's `cad/src/sheets.py`) builds drawing sheets as SVG and PDF in `cad/drawings/`.
- The GitHub Action in `.github/workflows/docs.yml` runs the checks on every push and attaches PDFs to a GitHub Release whenever a release tag is pushed.
- Public releases follow section 14: `python .kit/release_gate.py` must pass, and the release tag is `v0.<TRL>.0` (for example `v0.3.0` at TRL 3).

## 9. Technology Readiness Level (TRL)

Each project states its maturity as a Technology Readiness Level on the NASA and US DOE 1 to 9 scale. The TRL rates this specific design, not the underlying technology. A sand battery is commercial elsewhere, but a new sand battery design starts at TRL 2 until evidence shows otherwise.

| TRL | Definition | Evidence the repo must contain |
| --- | --- | --- |
| 1 | Basic principles observed | Problem statement (PRB) |
| 2 | Technology concept formulated | Draft precis (PRC) and requirements (REQ) |
| 3 | Analytical or experimental proof of concept | Calculation note (CAL), working build123d model with STEP export, drawing sheet (DWG), priced BOM with every unit cost filled in, prototype build plan (BLD) with pictures, `design_state: constructable` |
| 4 | Components validated in the lab | Test report (TST) with `environment: lab`, build log entries |
| 5 | Validated in a relevant environment | Test report (TST) with `environment: relevant` |
| 6 | System prototype demonstrated in a relevant environment | Precis at version 1.0 or later with status Released, a drawing at a lettered revision (Rev A or later), and a system-level TST with `environment: relevant` |
| 7 to 9 | Operational demonstration through proven in service | Beyond portfolio scope; claim only with a named deployment partner and evidence |

Rules:

- `project.yaml` records `trl` (current level), `trl_target` (the level the current effort aims for) and `trl_evidence` (the files that support the claim).
- `python .kit/render.py --check` fails if the evidence for the claimed TRL is missing. CI runs this check on every push.
- Documentation alone cannot go past TRL 3. TRL 4 and above require hardware and a test report.
- TRL and visibility are independent. A repo can be public at TRL 3 as a documented design ready to build.
- A change of TRL is recorded in the build log with the date and the evidence that justified it.

## 10. Portfolio phase and TRL cap

`.kit/PHASE.yaml` sets the current phase. During the **populate** phase every repo is capped at **TRL 3**: `trl` and `trl_target` may not exceed 3, and the check fails if they do. Every repo targets the cap: `trl_target` must equal 3, so a new repo is taken all the way to TRL 3 (scaffold, populate and advance, see `/to-trl3`). Work that belongs to TRL 4 or later (building or testing hardware, test articles, test plans and reports, build-log entries, purchasing lists, PCB layouts) must not be started. The prototype build plan (BLD, section 18) is TRL 3 paper work and is required. Where it already exists it is kept, flagged in the check output, and not extended. Only Amish changes `PHASE.yaml`.

Every repo carries a `CLAUDE.md` with the working rules for AI sessions: the TRL cap, decision rights (nothing is recorded as decided unless Amish decided it), one step per session, and a mandatory `docs/REVIEW.md` before stopping.

## 11. Concept media

Every repo at TRL 2 or above explains its idea visually. Media are generated from a build123d massing model with `.kit/concept.py`, never drawn by hand, so they stay in step with the design.

| File | Required | Purpose |
| --- | --- | --- |
| `media/hero.png` | TRL 2+ | Shaded isometric render with a 1.75 m person for scale; the website card image |
| `media/concept-blueprint.png` and `.pdf` | TRL 2+ | Blueprint concept sheet: orthographic and isometric views, scale, key figures, title block |
| `media/model.glb` and `media/viewer.html` | TRL 2+ | Interactive 3D viewer (glTF plus model-viewer) for the website |
| `media/cutaway.png` | When the inside matters | Section view showing internal parts |
| `media/exploded.png` | Recommended | Exploded view with numbered callouts matching the BOM |
| `media/flow.png` | When energy or material moves | System, energy or material flow diagram with losses |

Session commands in `.claude/commands/` (`/populate`, `/advance-trl3`, `/rein-in`, `/refresh-media`) carry the standard prompts, so every Claude Code session starts from the same instructions.

At TRL 2 a massing model is enough: correct overall proportions and main components. All concept media carry "CONCEPT, NOT FOR FABRICATION". The check warns when required media are missing at TRL 2 and fails at TRL 3.

## 12. Product renders

Every repo at TRL 3 shows the product as it would look, not only as a massing model.

- `cad/src/product_model.py` is the appearance model. It defines `product_parts()` (named parts with a shape and a material), `TITLE` ("Name: what it is") and `RENDER_VIEWS`. It is for renders only: every main dimension comes from `cad/src/model.py`, never typed in again.
- Where the appearance model departs from `model.py` (a chamfer, a label, a fastener drawn for realism), record the deviation in `docs/REVIEW.md` as "Proposed, awaiting Amish".
- Scale comes from context, not from a floating figure: a hand or forearm for handheld objects, and the posed mannequin (`mannequin()` in `.kit/context_parts.py`: stand, walk, push, ride, sit, reach) for anything a person uses at body scale.
- Renders are made with `.kit/export_views.py` (one scene per view) and `.kit/photoreal.py` (Blender Cycles), then captioned with `.kit/photo_caption.py`. Files are `media/render-<view>.png`; `media/render-hero.png` is required.
- Every caption names the project, the repository and the viewing direction, and carries "CONCEPT, NOT FOR FABRICATION".
- Captions never sit on the render. `.kit/photo_caption.py` adds a header band (title, concept label, repository) above the render and a footer band (view note) below it, wraps every line to the image width, and steps the font down to a floor before adding a line.
- The README opens with `media/render-hero.png`.
- Software-only and scene repositories (no single product) may use a scene render as the hero instead of a product model.

## 13. Storefront images

Two images, both made from `media/render-hero.png` by `python .kit/cards.py .`:

| File | Size | Purpose |
| --- | --- | --- |
| `media/card.png` | 800 x 800 | Square thumbnail for the organization profile page |
| `media/social-preview.png` | 1280 x 640, under 1 MB | GitHub social preview, shown when a repository link is shared |

- The social preview shows the area, name, one-line description, the first sentence of the pitch, the brand line and the repository address. Design Molecule repos read "Design Molecule · open hardware concept, TRL n"; OpenRatio repos read "OpenRatio · research and educational prototype, TRL n".
- GitHub has no API for the social preview. Upload it under the repository's Settings, Social preview, on release day.
- Regenerate both images whenever `render-hero.png` changes.

### Image quality

Every render, card and social preview must be clear and readable. `python .kit/image_qc.py` checks each one, and the release gate blocks on any failure:

| Check | Rule |
| --- | --- |
| Layout | Made by the current `photo_caption.py` or `cards.py`, which store the text layout in the PNG |
| Text inside the image | Every line at least 1.2 % of the image width from each edge; nothing runs off the side |
| No overlap | No line of text touches another line, and no caption text sits on the render |
| Text size | Render captions at least 1.05 % of the image width in pixel height (17 px at 1600 px); social preview text at least 16 px |
| Resolution | Renders at least 1200 px wide; card 800 x 800; social preview 1280 x 640 and under 1 MB |
| Sharpness | The render is not blurred or upscaled (edge sharpness at least 15 on the `image_qc.py` scale) |

Long titles and notes wrap to more lines rather than shrinking below the floor. The social preview shortens the pitch sentence with an ellipsis only if it cannot fit at the smallest size.

## 14. Public release

A repository goes public only when Amish approves it, and only after `python .kit/release_gate.py` passes. The gate checks:

1. `render.py --check` passes (document control, TRL cap, concept media).
2. Storefront: hero render, card, social preview under 1 MB, README leading with the hero, and every image passing the image quality check (section 13).
3. Issue templates in `.github/ISSUE_TEMPLATE/`: question, build report, design suggestion. The build report template restates that the design is a TRL 3 concept, not released for fabrication (OpenRatio: a research and educational prototype, not a medical device).
4. `CITATION.cff` valid, with an author ORCID.
5. License files match `project.yaml`.
6. No em dashes in the repository's own text.
7. BioMedical and OpenRatio repos use soft, non-clinical wording: "research and educational prototype, not a medical device".
8. No secrets anywhere in the history (gitleaks).
9. No links to sibling repositories that are still private.
10. REUSE files present (`REUSE.toml`, `LICENSES/`, `.github/workflows/reuse.yml`) and `reuse lint` passes (section 16).
11. `CITATION.cff` names exactly one license, because Zenodo rejects a list (section 17).

It warns, without blocking, when the README lacks a Safety heading or a "not for fabrication" statement, when `CITATION.cff` has no DOI yet, and when the README lacks the Zenodo DOI, REUSE or Software Heritage badge, so a person can confirm.

On release day, per repository:

- A signed, annotated tag `v0.<TRL>.0` on `main`.
- A GitHub release with short notes (what it is, TRL, status, licenses, how to cite) and a design pack, `<repo>-v0.<TRL>.0-design-pack.zip`, holding `cad/step`, `cad/drawings`, `docs/pdf`, `bom`, README, licenses and `CITATION.cff`.
- Description from the first sentences of `pitch` (350 characters at most), website `https://designmolecule.com` (OpenRatio: `https://openratio.ai`), topics from `project.yaml`.
- Before the first release, the repository is switched on in Zenodo (section 17), so the release is archived and gets a DOI.
- Visibility switched to public last, after the release exists.
- The social preview uploaded and the organization profile updated with the new cards.
- After the release: the concept DOI written to `CITATION.cff` and a Software Heritage save requested (section 17).

The internal working files (`CLAUDE.md`, `.kit/CLAUDE.md`, `.claude/commands/`, `docs/REVIEW.md`) stay public, and open "Proposed, awaiting Amish" items stay visible as open questions (Amish, 2026-09-27).

## 15. Authorship, citation and signing

- Amish Chadha is the author of every design, ORCID 0009-0000-8079-7141. Commits are authored as Amish Chadha <amish@designmolecule.com>.
- `CITATION.cff` lists Amish (with ORCID) first, then any credited contributors; `CONTRIBUTORS.md` and the README Credits section agree with it.
- `CITATION.cff` names one license: the hardware license (CERN-OHL-S-2.0), or the software license in a software-only repository. The full split between hardware and software licenses lives in `REUSE.toml` and the README. Once the repository is archived, `CITATION.cff` carries the concept DOI in `doi:`.
- Work done with Claude carries the trailer `Co-Authored-By: Claude <noreply@anthropic.com>` (with the model name), and the README Credits section says designs are developed with AI assistance.
- Every commit and tag pushed to GitHub is signed with Amish's SSH signing key, so GitHub shows it as Verified. Commits prepared elsewhere are re-signed on Amish's Mac before they are pushed.
- Once a repository is public, its history is never rewritten.
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

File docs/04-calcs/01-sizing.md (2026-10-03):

---
doc_id: GRR-CAL-001
title: GrowRider sizing calculations
project: GrowRider
doc_type: Calculation
version: "0.5"
status: Draft
date: '2026-10-02'
author: Amish Chadha
license: CERN-OHL-S-2.0
revisions:
- version: "0.1"
  date: '2026-09-25'
  author: Amish Chadha
  change: First issue for TRL 3 (fit, reach, steering, mass, rack, braking, service, cost, strength screen, drive and trip time)
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

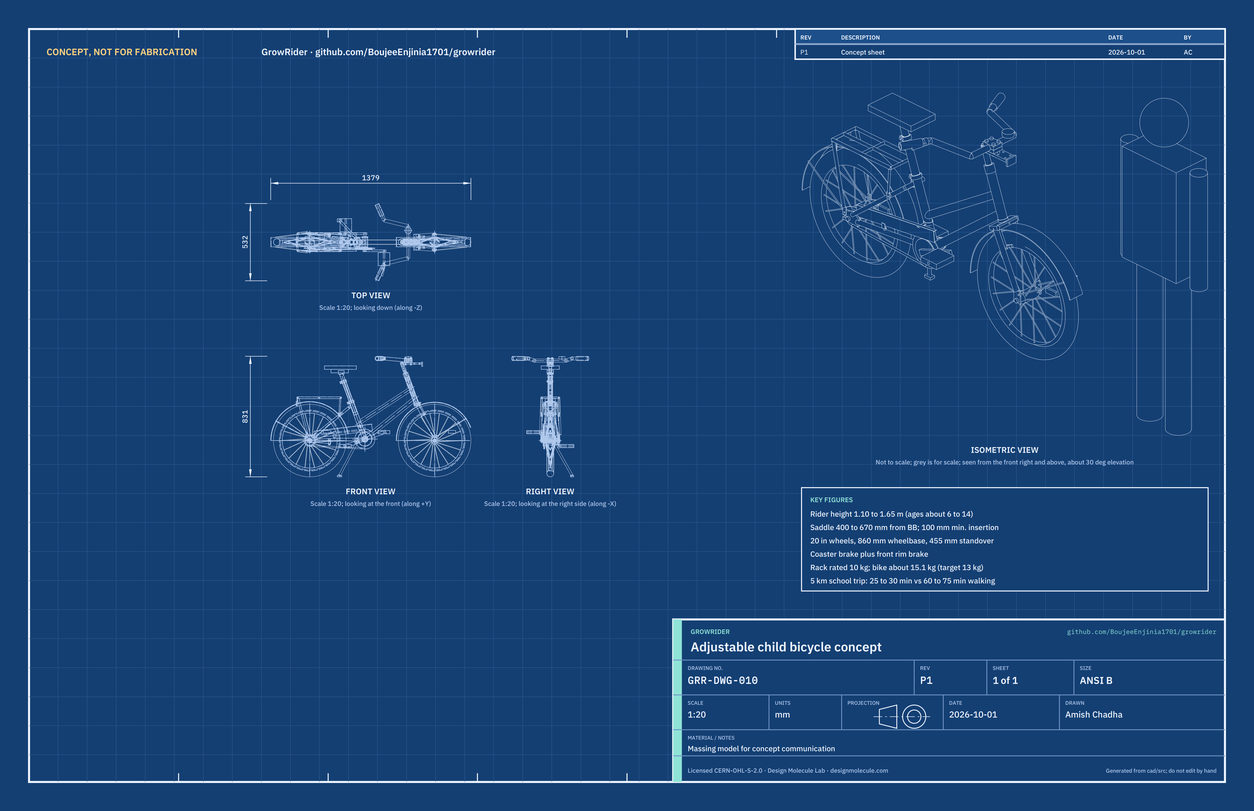
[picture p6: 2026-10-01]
media/concept-blueprint.png

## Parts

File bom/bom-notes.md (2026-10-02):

# BOM notes

Prices are indicative estimates by supplier type for a single prototype (TRL 3), not quotes. Every line is priced. Item numbers match the callouts in `media/exploded.png` and the parts in `cad/src/model.py`; lines 18 to 20 are not modeled in detail. `docs/04-calcs/sizing.py` reads this file and prints the totals quoted in GRR-CAL-001 [J1].

- `budget_usd` in `project.yaml` (USD 300) is a hypothetical value-engineering target, not a spending limit (Amish, 2026-10-01). Value-engineering target: USD 300. Estimated cost of the constructable design: USD 311 with the USD 12 helmet of line 20, which is supplied with every bike (decided by Amish, 2026-10-02), USD 11 over the target; USD 299 for the bike alone, lines 1 to 19 (USD 1 under the target). The cost drivers and savings worth trying are in the design decisions register (GRR-DEC-001).
- GRR-DDR-003 changes (design for construction, 2026-10-01, accepted by Amish on 2026-10-01): dropouts, stay cross bar, fender bridge, kickstand plate and bosses (line 1, USD 58 to 64); head plate, clamp block and bolts on the 22.0 mm quill (line 5, USD 14 to 20); long-reach caliper (line 12, USD 9 to 11); stop-screw collars, arm clip and fixings (line 19, USD 8 to 12). Together they add USD 18 and 0.7 kg (GRR-CAL-001 v0.4). Lines 2, 3, 6, 14 and 16 were respecified without a price change.
- GRR-DDR-002 changes (decided by Amish, 2026-09-25): chromoly 4130 main tubes (line 1, $40 to $58); chromoly steerer (line 2, $14 to $18); 29.2 x 1.8 mm chromoly sleeve (line 3, $9 to $13); chromoly quill (line 5, $10 to $14); alloy bar (line 6, $8 to $10); alloy front rim confirmed at the same price (line 7); alloy rear rim (line 8, $28 to $30); aluminium 6061-T6 rack (line 13, $10 to $14). Together they add $38 and save 0.9 kg (GRR-CAL-001 v0.2).
- The line 1 frame price covers tube and consumables only; a frame builder's labor is not included and would add to the estimated cost if paid.
- The largest cost lines are the chromoly frame (USD 64; USD 58 before GRR-DDR-003), the solid tires ($32 for the pair, decided 2026-09-25) and the rear wheel with coaster brake hub ($30).
- Earlier TRL 3 changes: the fork needs a steerer with 220 mm usable length (longer than a stock 20 in fork), the stem is a long quill with 235 mm below the clamp, an alloy front rim was preferred for wet braking (now decided), plastic fenders are preferred for mass, the chain is 86 links, and line 19 now includes the positive stop bolts for the sliding parts. None changed a price.
- Parts commonality: lines 3 (post), 6, 10 (pedals), 11, 12, 16, 17, 18 and the hub internals in line 8 are intended to match parts sold for regional adult roadsters. Lines 7, 8 (rims), 9 and 14 are specific to the 20 in wheel size, and lines 2, 3 (sleeve) and 5 are made or modified parts. This must be checked against a real parts list from a partner.
- Production cost at volume is not estimated. The $120 target (decided 2026-09-25) needs an estimate from a regional assembler.

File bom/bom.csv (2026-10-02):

item | qty | spec | supplier | unit_cost_usd | make_buy | notes
1 Step-through chromoly frame | 1 | Chromoly 4130 main tubes: 180 mm head tube (34 x 2.0 mm, 30.0 mm bore for 1 in JIS press-in cups), 280 mm seat tube (31.8 x 1.2 mm, 29.4 mm bore) with rear clamp slit and M5 stop screw hole, 31.8 x 0.9 mm down tube and 28.6 x 0.9 mm loop tube (twin down tubes); steel 19 x 1.2 mm chainstays and 16 x 1.2 mm seat stays on a 16 mm cross bar behind the seat tube; 6 mm steel track-end dropouts (110 mm apart) with M5 eyelets; 12 mm seat stay bridge; 4 mm kickstand plate; M5 bosses for the rack stays and chainguard; 68 mm BSA BB shell; powder coat, bright color | Self or local frame builder (tube from a steel stockholder) | 64.00 | make | Tube, plate and consumables for one prototype; builder labor not included; step-through decided 2026-09-25; chromoly main tubes decided 2026-09-25 (GRR-DDR-002, D7); dropouts, cross bar, bridge, kickstand plate and bosses added for construction (GRR-DDR-003); indicative
2 Fork | 1 | 20 in (ISO 406) fork, 30 mm offset, crown about 16 mm deep, slotted fork ends 100 mm apart with M5 eyelets, 1 in threaded chromoly steerer (25.4 x 1.6 mm, 22.2 mm bore) with 220 mm usable length above the crown, rim brake mounting hole through the crown | Bicycle parts wholesaler | 18.00 | buy | Chromoly steerer decided 2026-09-25 (GRR-DDR-002, D10); steerer longer than a stock 20 in fork; fork ends and crown depth specified for construction (GRR-DDR-003); indicative
3 Telescoping seat post | 1 | Two stages: 29.2 x 1.8 mm chromoly sleeve (25.6 mm bore), 250 mm long, with a 6 x 136 mm stop slot on its left side and its own clamp collar; 25.4 x 1.8 mm steel seat post, 280 mm long, with a 6 x 146 mm stop slot on its right side; minimum insertion marks at 100 mm on both | Bicycle parts wholesaler plus self | 13.00 | buy | Sleeve is a made part (1.8 mm wall decided 2026-09-25, GRR-DDR-002, D10); 25.4 mm post is common to roadsters and is slotted for its stop screw (GRR-DDR-003); indicative
4 Saddle | 1 | Child size, light color vinyl cover, standard rail clamp, about 60 mm stack | Bicycle parts wholesaler | 7.00 | buy | Indicative price
5 Telescoping stem | 1 | 22.0 x 2.0 mm chromoly quill, 240 mm below its top, 120 mm travel, minimum insertion mark at 100 mm, welded top cap and expander wedge, M8 expander bolt with 13 mm head; 10 mm chromoly head plate, 127 x 44 mm, welded to the quill with four M8 tapped holes at each of two bar positions (45 or 105 mm ahead of the steering axis); two-piece aluminium bar clamp block 54 x 44 x 30 mm; four M8 x 40 bolts with 13 mm heads | Self from a standard long quill stem | 20.00 | make | Chromoly quill decided 2026-09-25 (GRR-DDR-002, D10); 22.0 mm quill to fit the 22.2 mm steerer bore, head plate and clamp block make the two bar positions buildable (GRR-DDR-003); indicative
6 Handlebar and grips | 1 | 22.2 mm alloy swept-back roadster-style bar, 520 mm wide, about 205 mm sweep and 15 mm rise; rubber grips with end plugs | Bicycle parts wholesaler | 10.00 | buy | Alloy bar decided 2026-09-25 (GRR-DDR-002, D7); sweep and rise chosen so the grips sit where the concept put them (GRR-DDR-003); indicative
7 Front wheel | 1 | 20 in (ISO 406) alloy rim, 28 spokes, nutted hub, 15 mm axle nuts | Bicycle parts wholesaler | 15.00 | buy | Alloy rim decided 2026-09-25 for wet braking (GRR-DDR-002, D8); indicative
8 Rear wheel with coaster brake hub | 1 | 20 in (ISO 406) alloy rim, 36 spokes, single-speed coaster brake hub with reaction arm, 18T sprocket | Bicycle parts wholesaler | 30.00 | buy | Alloy rim decided 2026-09-25 (GRR-DDR-002, D7); hub type common on regional roadsters (to confirm); brake ratio still needed (D9); indicative
9 Puncture-proof tire | 2 | 20 x 1.95 in solid or airless tire, about 1.1 kg each | Specialist tire supplier (online) | 16.00 | buy | Solid or airless decided 2026-09-25; indicative
10 Crankset with pedals | 1 | 140 mm steel cranks, 32T chainring, 9/16 in pedal threads, reflective pedals | Bicycle parts wholesaler | 16.00 | buy | One crank length decided 2026-09-25; adult pedals fit; indicative
11 Chain | 1 | 1/2 x 1/8 in single-speed chain, about 86 links | Bicycle parts wholesaler | 5.00 | buy | Same chain as roadsters; sprocket included with the hub in line 8; indicative
12 Front rim brake and lever | 1 | Long-reach side-pull caliper, reach range covering 84 mm, nutted mounting bolt; short-reach child lever with reach adjust, cable and housing with slack for 120 mm of stem travel | Bicycle parts wholesaler | 11.00 | buy | Coaster plus front rim brake decided 2026-09-25; reach set by the fork crown and fender (GRR-DDR-003); indicative
13 Rear rack | 1 | 12 x 1.5 mm aluminium 6061-T6 tube, welded, 300 x 120 mm platform, 10 kg rating marked, no footrests | Self or local frame builder | 14.00 | make | Aluminium decided 2026-09-25 (GRR-DDR-002, D7); needs a builder who can TIG weld aluminium, or a bought rack of this size; indicative
14 Fenders | 1 | Pair, 20 in, 64 mm wide, plastic preferred (steel alternative); rear 16 mm and front 12 mm from the tire; wire stays to the dropout and fork-end eyelets; L brackets to the seat stay bridge and the caliper bolt | Bicycle parts wholesaler | 7.00 | buy | Indicative price
15 Chainguard | 1 | Full-length plate guard over the upper chain run | Bicycle parts wholesaler | 4.00 | buy | Protects uniforms and skirts; indicative
16 Kickstand | 1 | Centre-mount kickstand on the kickstand plate behind the BB, M10 bolt, leg on the left, adjustable length | Bicycle parts wholesaler | 5.00 | buy | Indicative price
17 Reflectors and bell | 1 | Front white, rear red, two spoke reflectors per wheel, bell | Bicycle parts wholesaler | 6.00 | buy | Pedal reflectors included in line 10; indicative
18 Bottom bracket and headset | 1 | 1 in threaded headset (32 mm locknut), cup and cone or cartridge bottom bracket for a 68 mm shell | Bicycle parts wholesaler | 10.00 | buy | Not modeled in detail; indicative
19 Hardware and consumables | 1 | Two clamp collars (31.8 and 29.8 mm) each drilled and tapped M5 for a dog-point stop screw, two M5 x 10 dog-point stop screws, M8 collar bolts, coaster arm clip with M6 bolt, M5 bolts for the rack and fender stays, chainguard seat tube clip, grease, paint touch-up, cable ends, warning labels | Self (hardware store) | 12.00 | buy | Stop screws and collars replace the concept's positive stop bolts (GRR-DDR-003); not modeled in full; indicative
20 Child helmet | 1 | Adjustable, ventilated, sized for about 48 to 58 cm heads | Safety equipment supplier | 12.00 | buy | Not modeled; supplied with every bike through the partner program (decided 2026-10-02); indicative

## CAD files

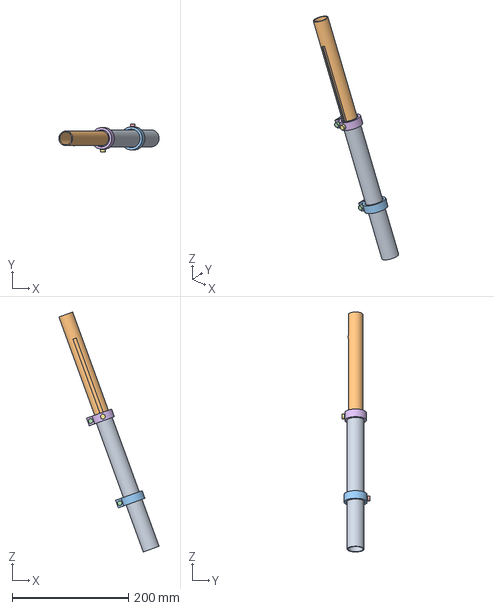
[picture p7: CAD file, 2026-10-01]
cad/step/seat-post-assembly.step
172.7 x 48.5 x 413.4 mm

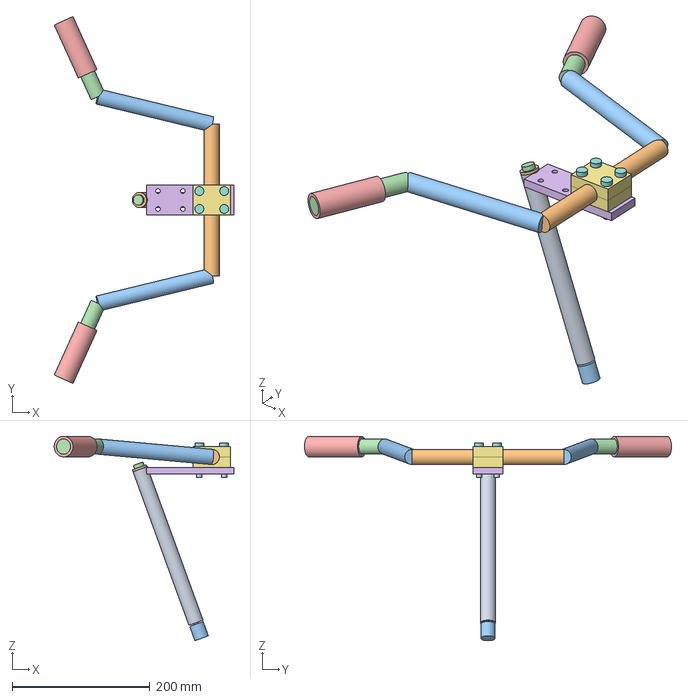
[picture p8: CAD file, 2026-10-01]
cad/step/stem-and-bar.step
260.7 x 532.4 x 296.7 mm

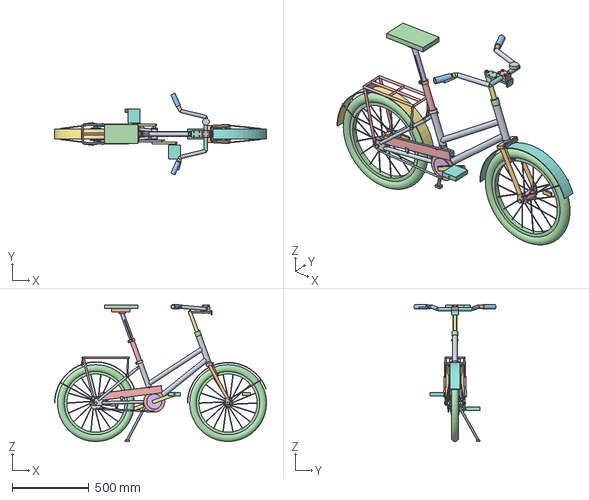
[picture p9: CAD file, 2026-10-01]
cad/step/growrider-large.step
1378.9 x 532.4 x 891.7 mm

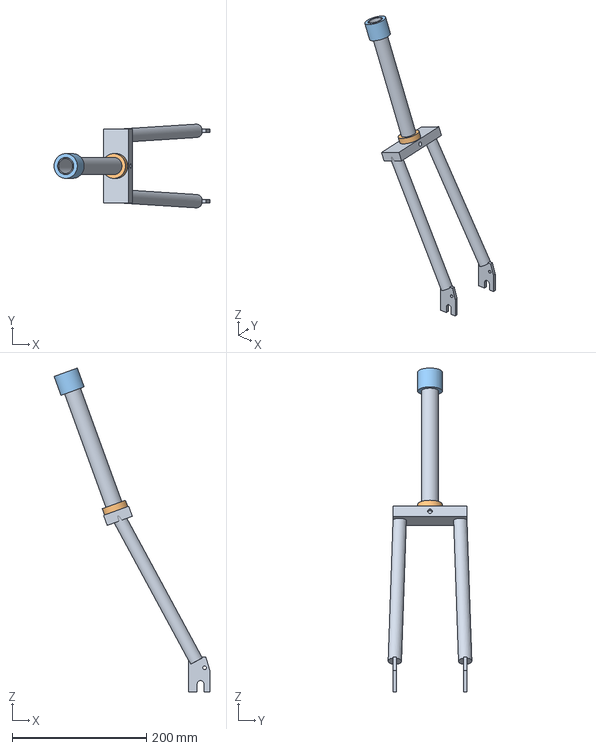
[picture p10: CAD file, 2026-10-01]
cad/step/fork.step
232.6 x 125.0 x 483.5 mm

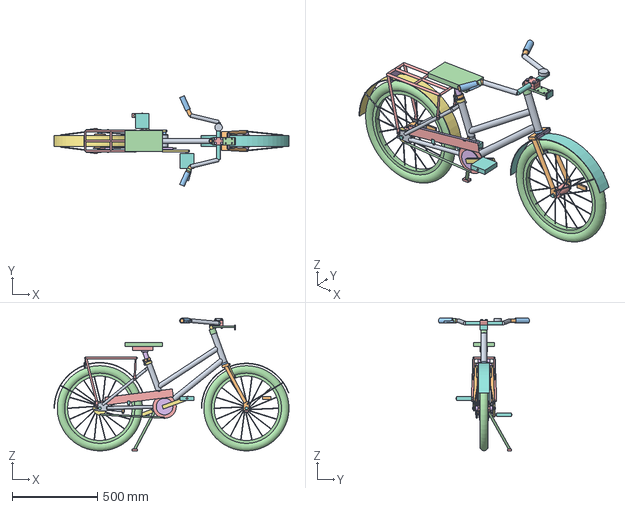
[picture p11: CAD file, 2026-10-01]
cad/step/growrider-small.step
1378.9 x 532.4 x 778.9 mm

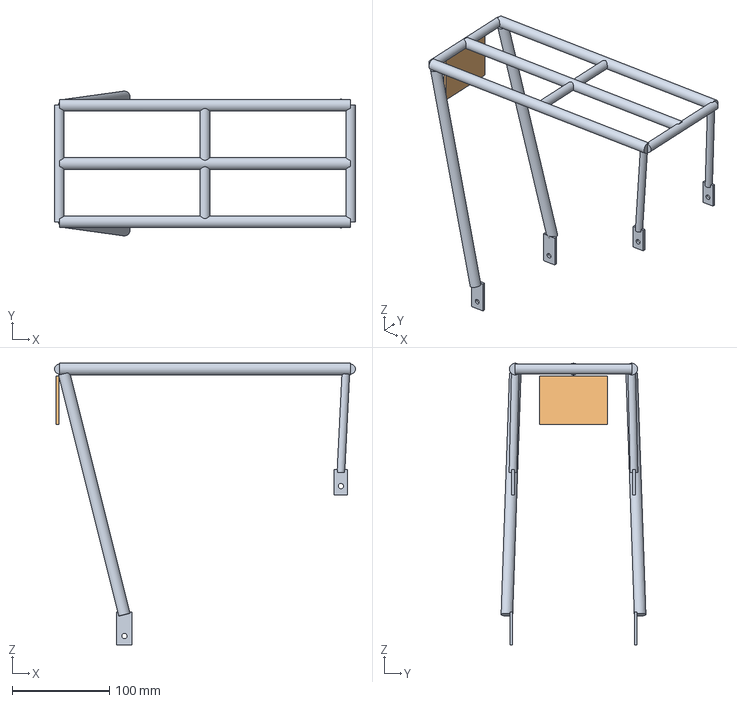
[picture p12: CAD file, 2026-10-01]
cad/step/rack.step
310.0 x 149.2 x 290.0 mm

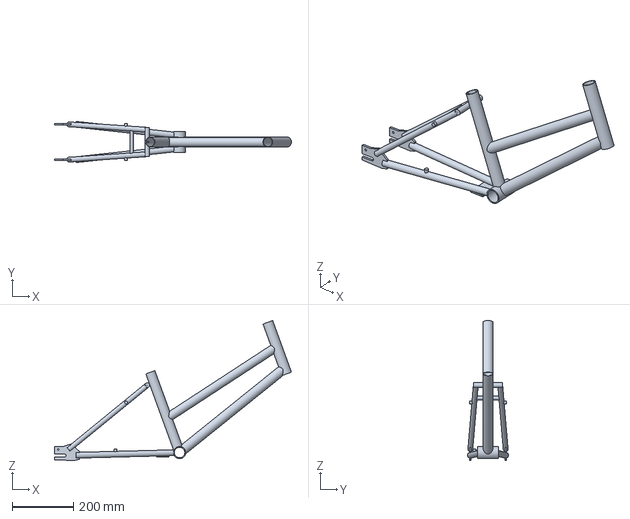
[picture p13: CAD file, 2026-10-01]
cad/step/frame.step
776.6 x 134.9 x 458.8 mm

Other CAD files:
cad/stl/fork.stl
cad/stl/frame.stl
cad/stl/growrider-large.stl
cad/stl/growrider-small.stl
cad/stl/rack.stl
cad/stl/seat-post-assembly.stl
cad/stl/stem-and-bar.stl

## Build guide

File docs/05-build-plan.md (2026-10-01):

---
doc_id: GRR-BLD-001
title: GrowRider prototype build plan
project: GrowRider
doc_type: Build plan
version: "0.2"
status: Draft
date: '2026-10-01'
author: Amish Chadha
license: CERN-OHL-S-2.0
revisions:
  - version: "0.1"
    date: '2026-10-01'
    author: Amish Chadha
    change: First build plan, with pictures by component and step; design made constructable (GRR-DDR-003)
  - version: "0.2"
    date: '2026-10-01'
    author: Amish Chadha
    change: GRR-DDR-003 accepted by Amish; painted height scales on the sleeve and quill, a bright painted band above the quill's insertion mark, and the name screen printed on the chainguard
---

# GrowRider prototype build plan

**Plan, not yet built.** How to build the first proof-of-concept prototype, component by component. Building and testing to it is TRL 4 work. Decisions still to be made are kept in the design decisions register ([docs/06-design-decisions.md](06-design-decisions.md)), not here.

## 1. What you are building

Figure 1. Every component, pulled apart and numbered in build order

*Figure 1. Every component pulled apart and numbered in build order, with the bike set for a 1.38 m rider.*

The prototype is one GrowRider: a step-through children's bicycle on 20 in wheels whose seat post and handlebar stem slide to fit riders from about 1.10 to 1.65 m tall. Figure 1 shows its 24 components in the order you make or fit them. Eight are made in a frame builder's workshop: the two rear dropouts, the brazed frame, the seat post sleeve, the two clamp collars with their stop screws, the slotted seat post, the quill stem with its welded head plate, the aluminium bar clamp block and the welded aluminium rack. Everything else is bought and fitted: fork, headset, bottom bracket, wheels with a coaster brake hub, solid tires, crankset, chain, front brake, saddle, handlebar, fenders, chainguard, kickstand, reflectors and bell. The work is cutting and mitring steel tube, cutting plate, brazing or TIG welding chromoly on a jig, reaming, drilling and filing slots, TIG welding aluminium, and ordinary bicycle assembly. The parts cost about USD 299 for the bike, from the bill of materials.

> **Safety:** This bicycle is for children, who will ride it on roads shared with motor traffic. Nobody may ride the prototype: the frame, fork, seat post, stem, rack and brakes must first pass the tests of ISO 4210-2, which is TRL 4 work. Brazing and welding chromoly and aluminium need training, fume extraction and fire precautions. Cut tube and plate edges are sharp; deburr everything. The sliding seat post and stem must never be set above their minimum insertion marks.

## 2. What changed to make it buildable

The concept showed what the bike does; some of its parts could not be made, fitted or fixed as drawn. Each change below keeps what the bike does (the same wheels, frame geometry, fit range, bar heights, reach, brakes and rack), and all of them are recorded in decision record GRR-DDR-003, accepted by Amish on 2026-10-01.

*Table 1. Changes from the concept.*

| Component | The concept had | The buildable design has | Why |
| --- | --- | --- | --- |
| Rear dropouts | Plain blocks 105 mm apart, no slot | 6 mm plates with a slot open to the rear, 110 mm apart, with an eyelet (Figure 2) | The axle slides back to tension the chain of a single-speed coaster hub |
| Seat stays | Joined the seat tube where the clamp collar sits | Joined to a cross bar 25 mm lower, which holds them 80 mm apart (Figure 6) | The collar closes on plain tube, and the rear fender passes between the stays |
| Sliding seat post | "Positive stop bolts" with no way to fit them | A stop screw in each clamp collar riding in a slot in the part inside (Figures 10 and 12) | Each stage stops with 100 mm still inserted and cannot be pulled past it |
| Head tube | 31 mm bore | 30 mm bore (34 x 2.0 mm tube) | Standard 1 in headset cups press into it |
| Quill stem | 22.2 mm quill, which cannot slide in the 22.2 mm steerer bore; a head at 0 or 60 mm that no single part could be | 22.0 mm quill with a welded head plate; a bar clamp block bolted at one of two positions (Figures 13 and 16) | The quill slides; the two bar positions are one part; the grips sit where the concept had them |
| Handlebar | 160 mm sweep, 25 mm rise | 205 mm sweep, 15 mm rise | Keeps the grips in place with the clamp block ahead of the expander bolt |
| Rack | Struts and stays ending in the air; front end under the saddle | Tabs bolted to the dropout eyelets and to bosses on the seat stays; 30 mm lower (Figure 17) | Four bolted fixings; the saddle clears the rack at the lowest setting |
| Front fender and caliper | Fender passing under a crown it did not fit under; caliper with no reach given | A crown 16 mm deep, the front fender 12 mm off the tire, a long-reach caliper of about 84 mm (Figure 18) | Everything fits under the crown on one bolt |
| Coaster brake arm, kickstand, chainguard | No fixings | Arm clip on the chainstay; kickstand plate under the chainstays; chainguard clip and boss (Figures 7 and 19) | Each part is held to the frame |
| Chain line | 48 mm, which put the sprocket into the chainstay | 42 mm, chainstays placed to suit | The sprocket, chainring and chain clear the frame by 2 mm or more |

## 3. Making the components

Make and check each component before the assembly step that needs it. Sizes are in millimetres. "Left" and "right" are as the rider sits; the chain is on the right. Workshop tolerance is 0.5 mm unless a step says otherwise; drawings do not carry tolerances before TRL 4.

### 3.1 Rear dropouts (make 2: a left and a right)

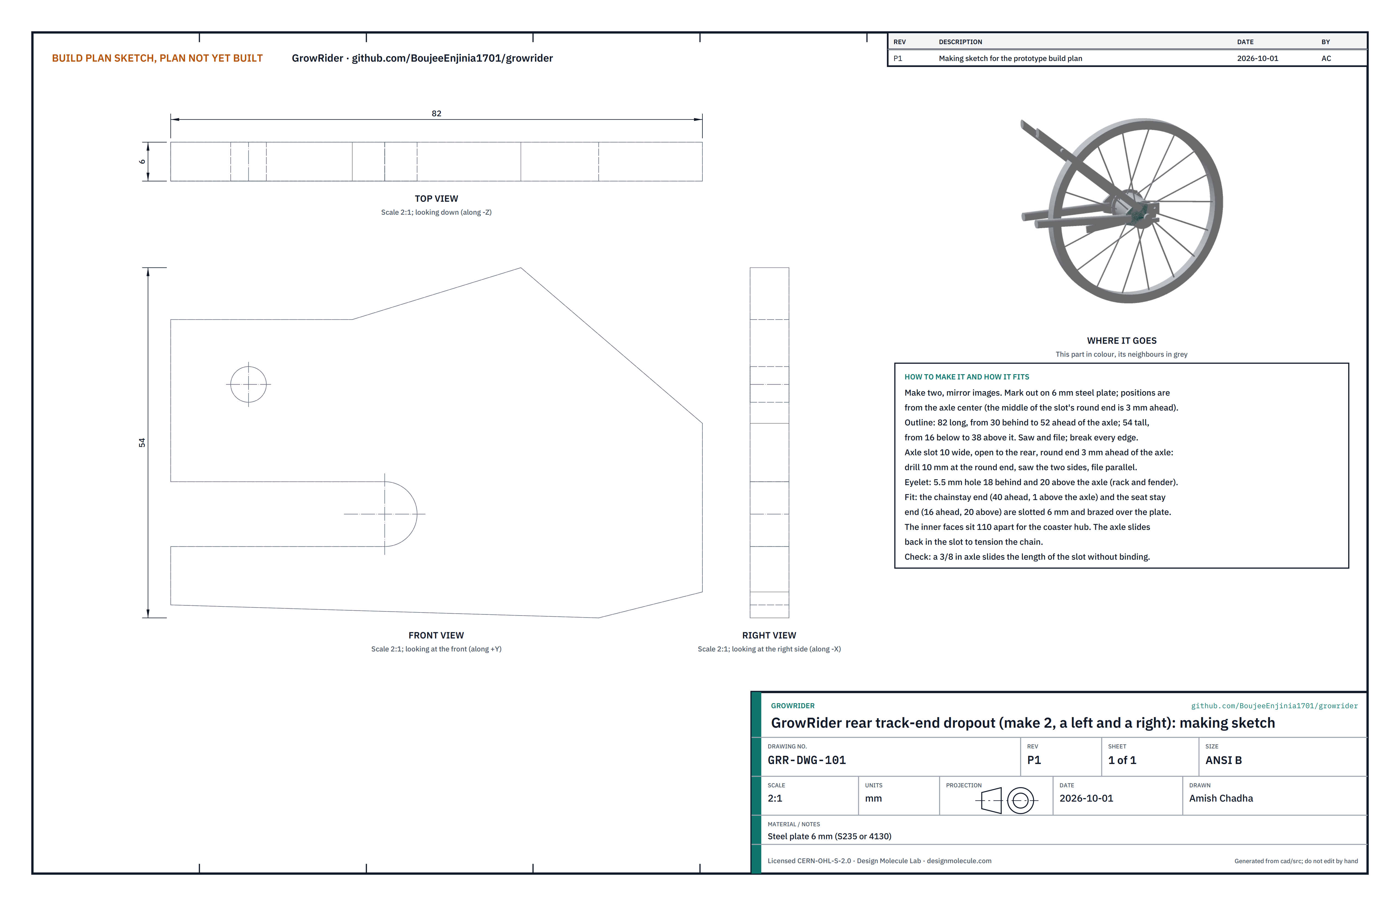
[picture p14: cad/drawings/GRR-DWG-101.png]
Figure 2. Making sketch of the rear dropout


*Figure 2. Rear dropout making sketch (GRR-DWG-101).*

**What it is and what it is made from.** The flat plate at each end of the rear stays that holds the rear axle. Steel plate 6 mm thick (S235, or 4130 to match the frame), 82 x 54 mm blanks.

**How to make it.**

1. Mark the outline on the plate, measuring from the axle center: 30 behind it to 52 ahead, 16 below to 38 above, with the upper front corner cut down to the front edge as Figure 2 shows.
2. Saw and file to the line. Break every edge.
3. Drill 10 mm with its center 3 mm ahead of the axle center: this is the round end of the slot.
4. Saw the two sides of the slot from the rear edge to the hole, 10 apart, and file them straight and parallel.
5. Drill the eyelet 5.5 mm, 18 behind and 20 above the axle center.
6. Make the second plate as a mirror image (the eyelet is in the same place; only the sides are swapped).

**How it fits the parts next to it.**

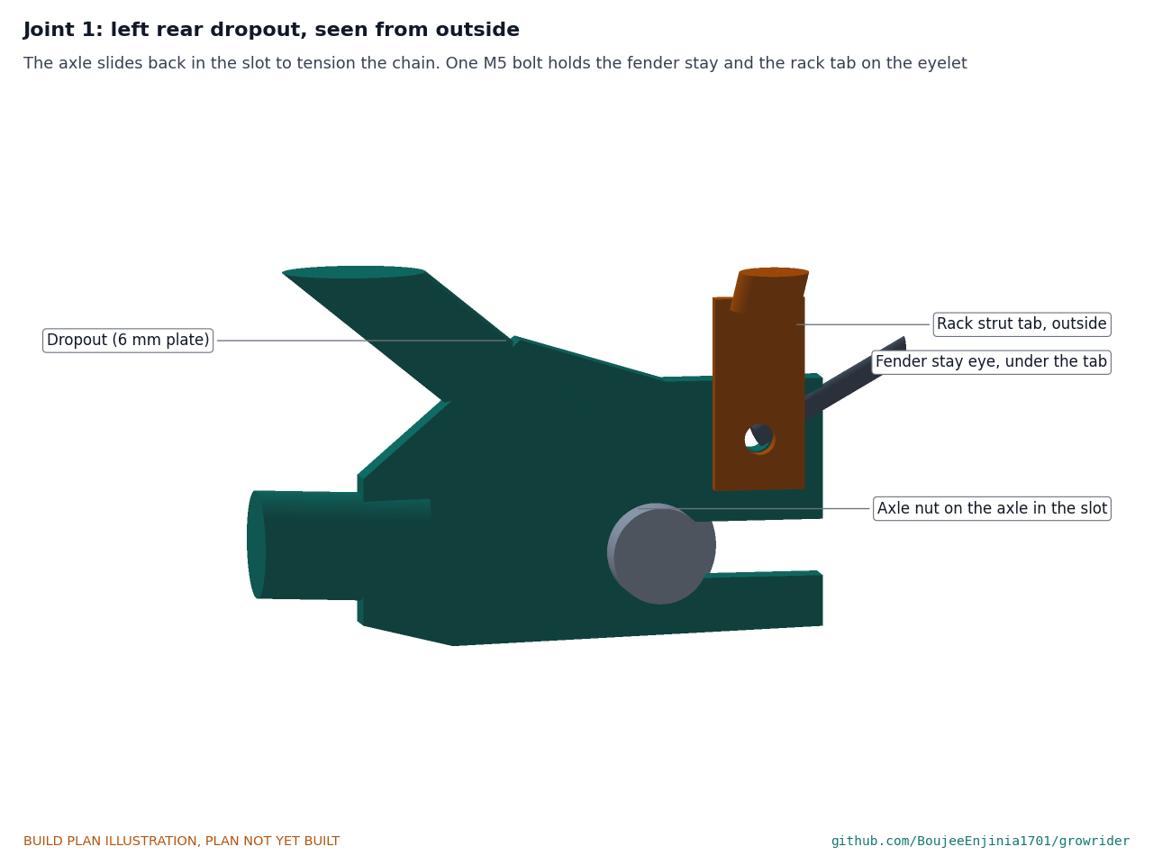
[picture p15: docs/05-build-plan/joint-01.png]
Figure 3. Joint 1: left rear dropout, seen from outside


*Figure 3. The axle sits in the slot and slides back to tension the chain; one M5 bolt holds the fender stay and the rack strut tab on the eyelet.*

The chainstay end and the seat stay end are each slotted 6 mm and brazed over the plate: the chainstay 40 ahead of the axle and level with it, the seat stay 16 ahead and 20 above. The two plates' inner faces are 110 apart, which is the width of the coaster hub over its locknuts. The rear axle nuts bear on the outer faces.

**Check before moving on.** A 3/8 in axle slides the full length of the slot without binding.

### 3.2 Frame

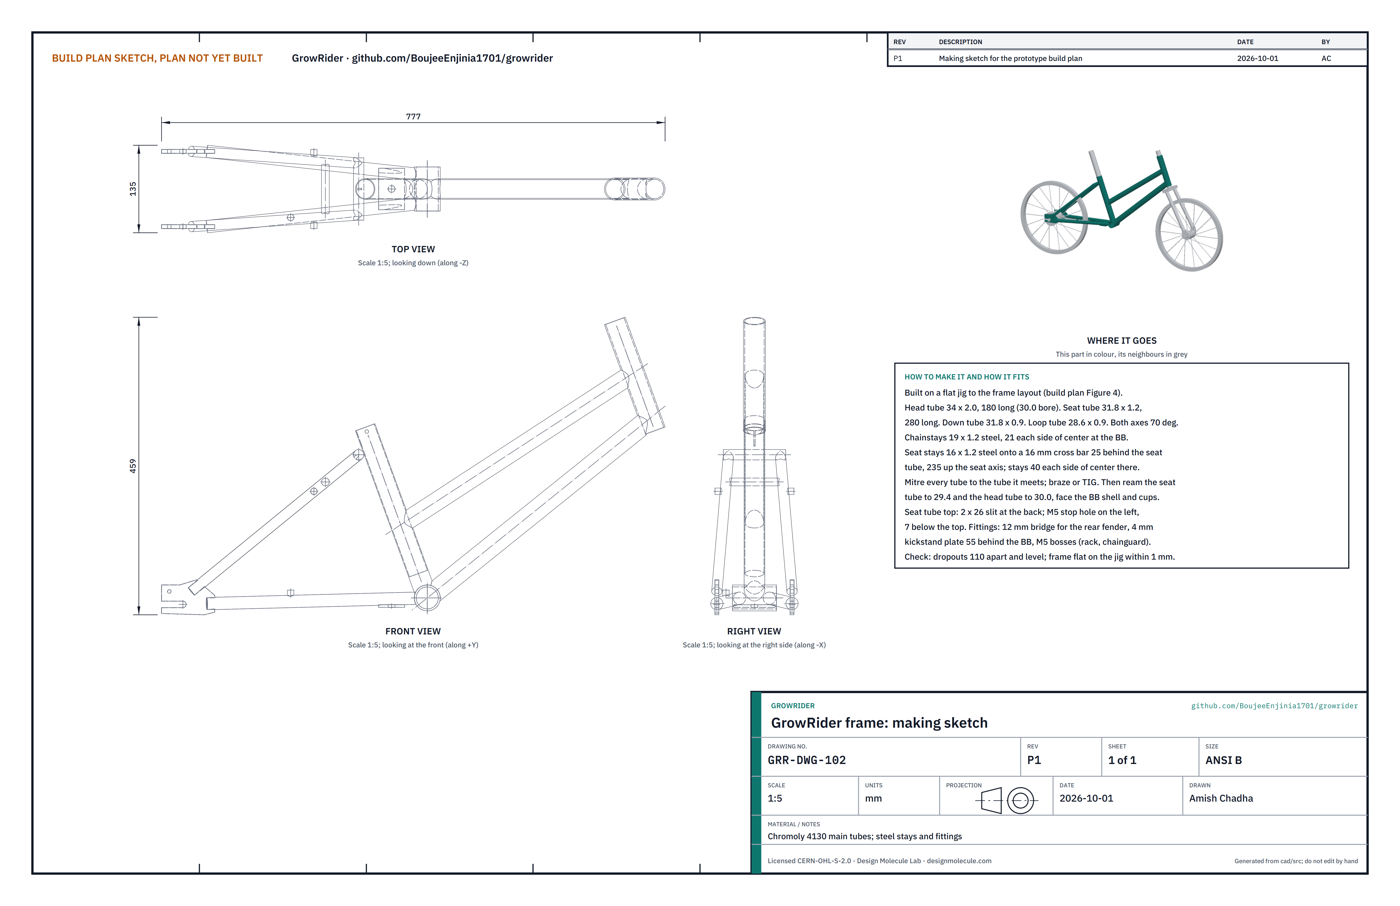
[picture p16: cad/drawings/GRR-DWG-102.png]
Figure 4. Making sketch of the frame


*Figure 4. Frame making sketch (GRR-DWG-102).*

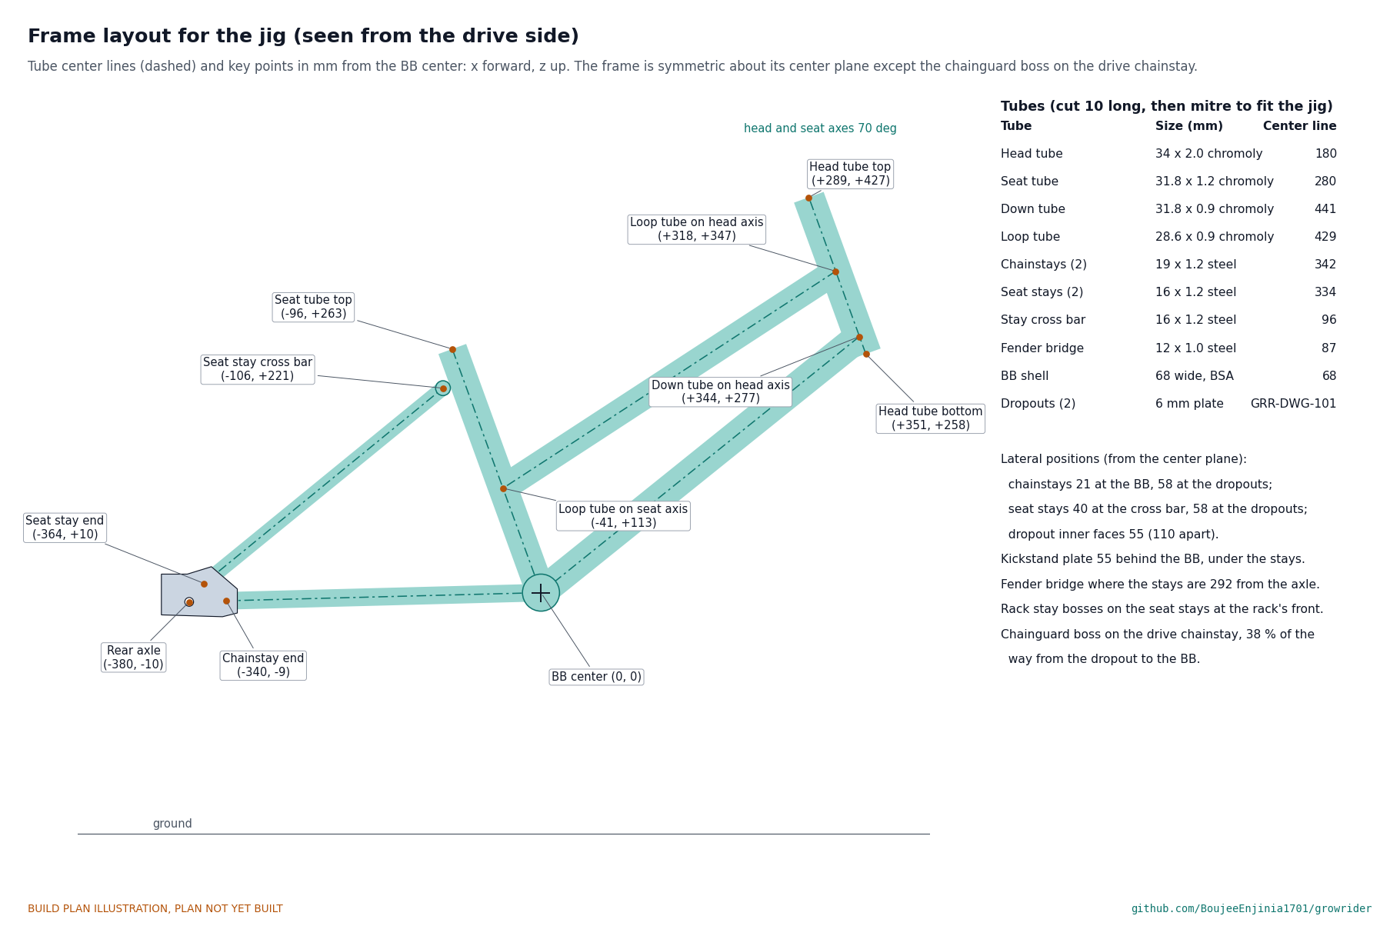
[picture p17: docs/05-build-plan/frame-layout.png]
Figure 5. Frame layout for the jig


*Figure 5. Tube center lines and key points from the bottom bracket center, for setting up the jig.*

**What it is and what it is made from.** The step-through frame: head tube, seat tube, down tube and a second, higher "loop" tube between them (the twin down tubes), the bottom bracket shell, two chainstays, two seat stays on a cross bar, and the dropouts. Chromoly 4130 tube for the main tubes: head tube 34 x 2.0, seat tube 31.8 x 1.2, down tube 31.8 x 0.9, loop tube 28.6 x 0.9. Steel tube for the stays (chainstays 19 x 1.2, seat stays and cross bar 16 x 1.2, fender bridge 12 x 1.0). A 68 mm threaded (BSA) bottom bracket shell, bought. Small fittings from 4 mm steel plate and M5 brazing bosses.

**How to make it.**

1. Set up a flat frame jig to Figure 5. Every position is in millimetres from the bottom bracket center: forward and up. The head and seat axes both lean back 70° from the ground.
2. Cut each tube 10 longer than its center-line length in Figure 5, then file the mitre at each end to fit the tube it meets, checking on the jig. Mitre the down tube and loop tube onto the head tube and the bottom bracket shell or seat tube, never into the bore.
3. The down tube meets the head tube with its edge at least 3 above the head tube's lower end, so the lower headset cup has a clean round end to press into.
4. Tack the front triangle (head tube, seat tube, down tube, loop tube, shell) on the jig, check it is flat, then braze or TIG weld it.
5. Chainstays: 21 each side of center at the shell, 58 each side at the dropouts; slot each rear end 6 wide and 20 deep for the dropout plate.
6. Seat stays: braze the cross bar across the back of the seat tube, its center 235 up the seat axis and 25 behind the seat tube's center line; the stays meet it 40 each side of center and run to the dropouts, 58 each side, each slotted 6 wide for the plate.
7. Hold the two dropouts on a 3/8 in dummy axle with their inner faces 110 apart and centered, and braze the stays to them.
8. Fittings: the 12 mm fender bridge between the seat stays where they are 292 from the axle; the kickstand plate (40 x 64 x 4) under both chainstays, 55 behind the bottom bracket center, with a 10.5 hole in its middle; an M5 boss on the outside of each seat stay at the rack's front end; an M5 boss on top of the right chainstay, 38 % of the way from the dropout to the bottom bracket, for the chainguard.
9. Seat tube top: saw a 2 wide, 26 long slit at the back so the collar can close it, and drill a 5.5 hole on the left side, 7 below the top, for the stop screw.
10. After brazing: ream the seat tube to 29.4 down to the bottom bracket shell, ream the head tube ends to 30.0 and face them square, chase and face the bottom bracket threads. Clean off flux, and powder coat.

**How it fits the parts next to it.**

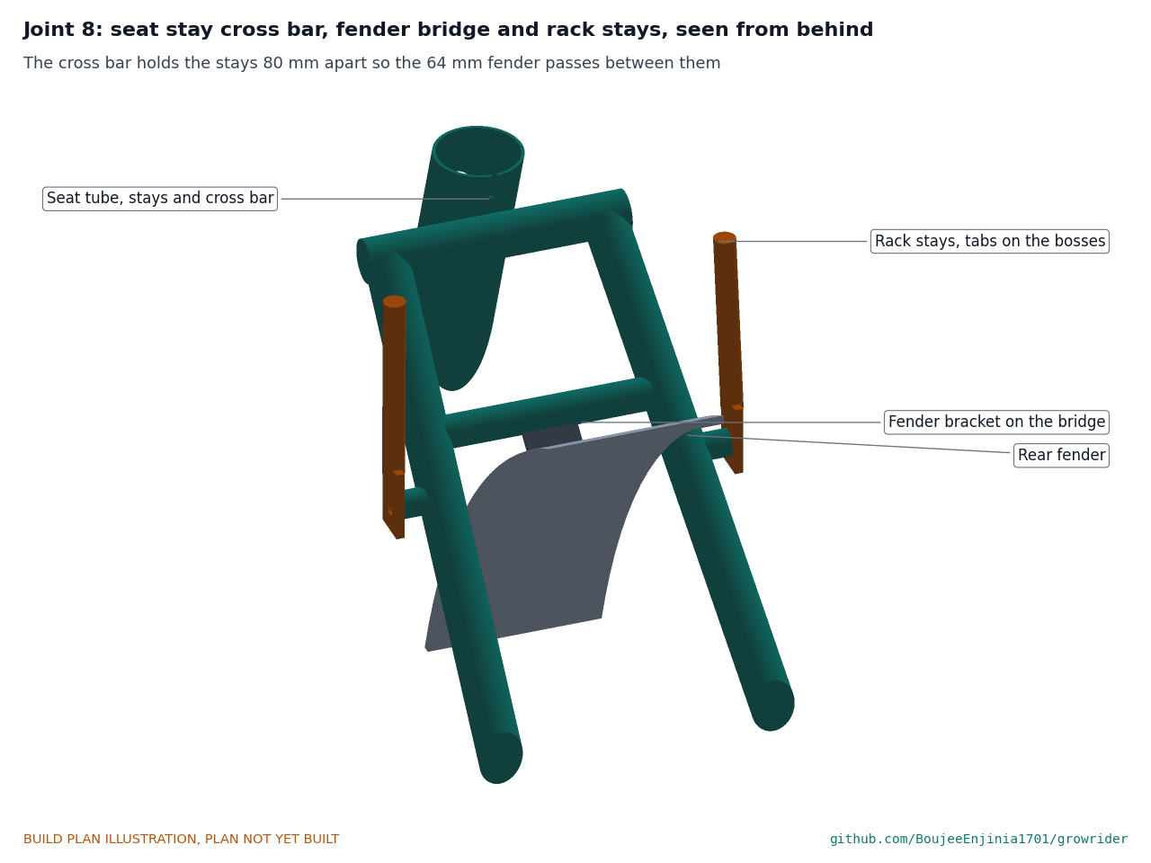
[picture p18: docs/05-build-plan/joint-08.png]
Figure 6. Joint 8: seat stay cross bar, fender bridge and rack stay


*Figure 6. The cross bar holds the seat stays 80 apart so the 64 wide fender passes between them; the rack's front stays bolt to bosses on the seat stays.*

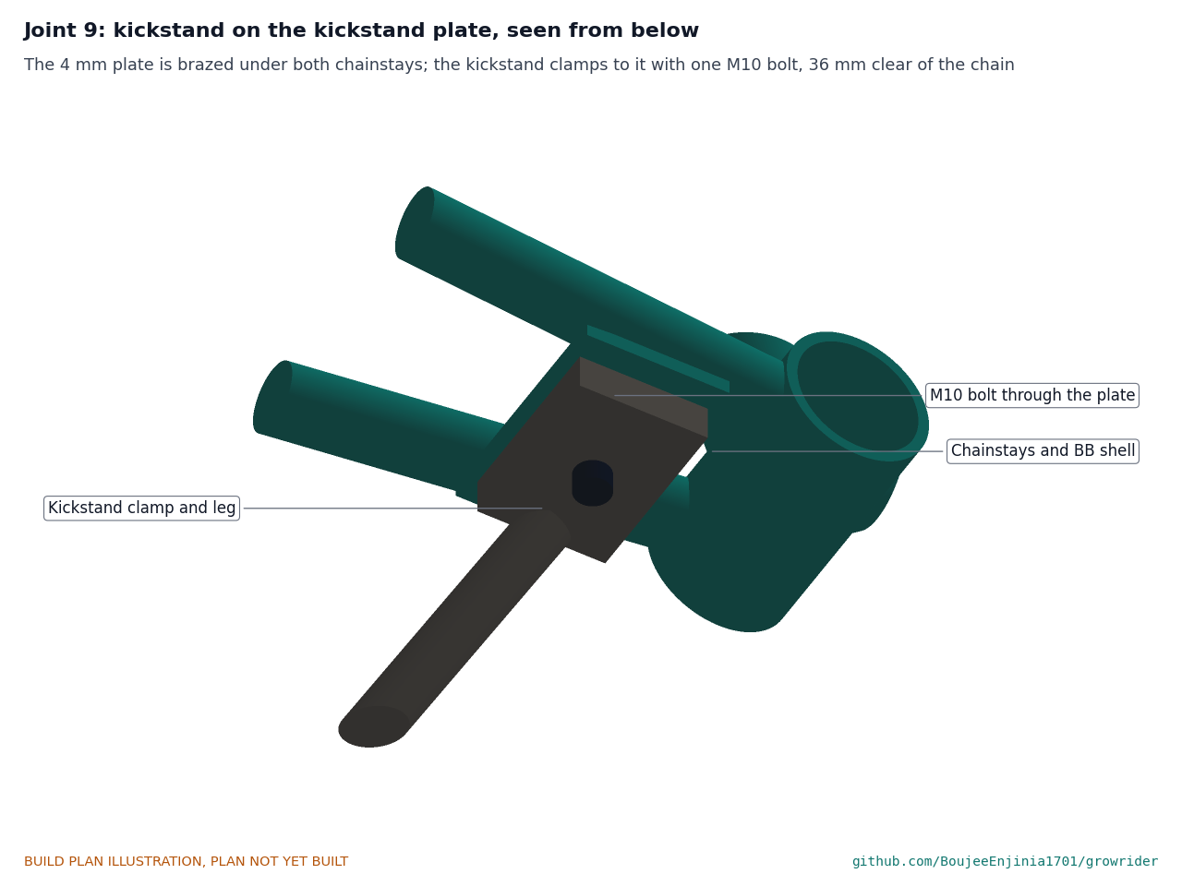
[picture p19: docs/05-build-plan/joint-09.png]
Figure 7. Joint 9: kickstand on the kickstand plate


*Figure 7. The kickstand plate is brazed under both chainstays; the kickstand clamps to it with one M10 bolt and clears the chain.*

The sleeve slides in the reamed seat tube with 0.2 clearance on the diameter. The headset cups press into the reamed head tube. The bottom bracket threads into the shell. The rack, fenders, chainguard and kickstand all bolt to the bosses, bridge, plate and eyelets named above.

**Check before moving on.** On the jig or a flat table: the dropouts are centered on the frame's center plane within 1, level, and 110 apart; the head and seat tubes lie in the frame's center plane within 1; the sleeve slides the full depth of the seat tube.

### 3.3 Seat post sleeve

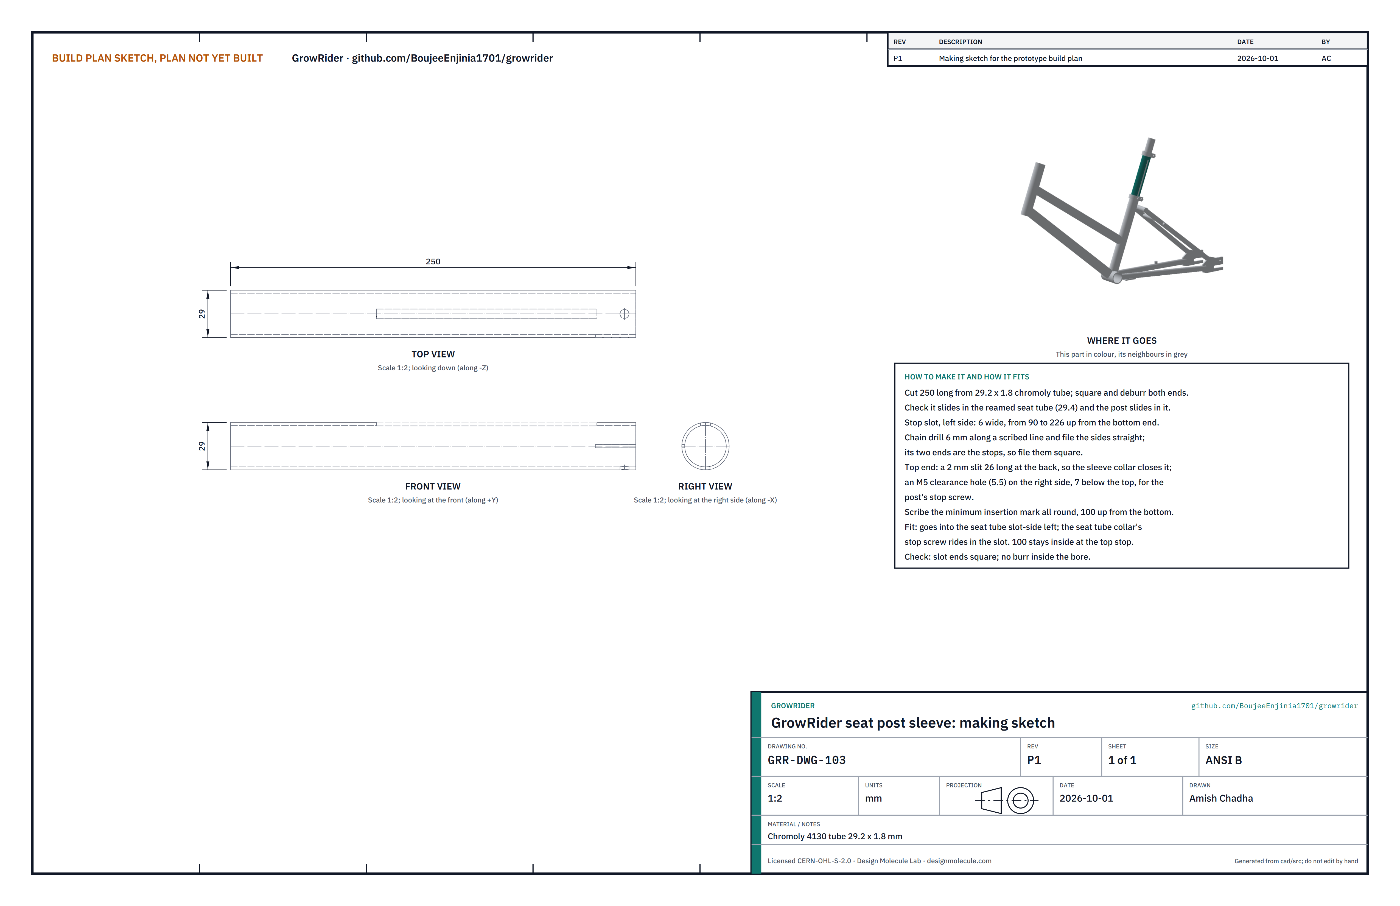
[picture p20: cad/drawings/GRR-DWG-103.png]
Figure 8. Making sketch of the seat post sleeve


*Figure 8. Seat post sleeve making sketch (GRR-DWG-103), drawn lying down with its slot facing up.*

**What it is and what it is made from.** The first sliding stage: a tube that slides in the seat tube and that the seat post slides in. Chromoly 4130 tube 29.2 x 1.8, 250 long.

**How to make it.**

1. Cut 250 long; square and deburr both ends inside and out.
2. On the left side, scribe a line along the tube and mark a slot 6 wide from 90 to 226 up from the bottom end.
3. Chain drill 6 holes along the line and file the slot's sides straight. File its two ends square: they are the stops.
4. At the top end, saw a 2 wide, 26 long slit at the back, and drill a 5.5 hole on the right side, 7 below the top, for the post's stop screw.
5. Scribe the minimum insertion mark all the way round, 100 up from the bottom end.
6. Paint a height scale on the part that shows above the seat tube: a band every 20 mm and a longer band every 60 mm, so a setting can be noted and reset.

**How it fits the parts next to it.** It slides in the seat tube, slot to the left, and the seat tube collar's stop screw rides in the slot (Figure 10). The seat post slides inside it (Figure 12).

**Check before moving on.** The slot ends are square; no burr inside the bore; the post slides through the whole sleeve.

### 3.4 Clamp collars with stop screws (make 2)

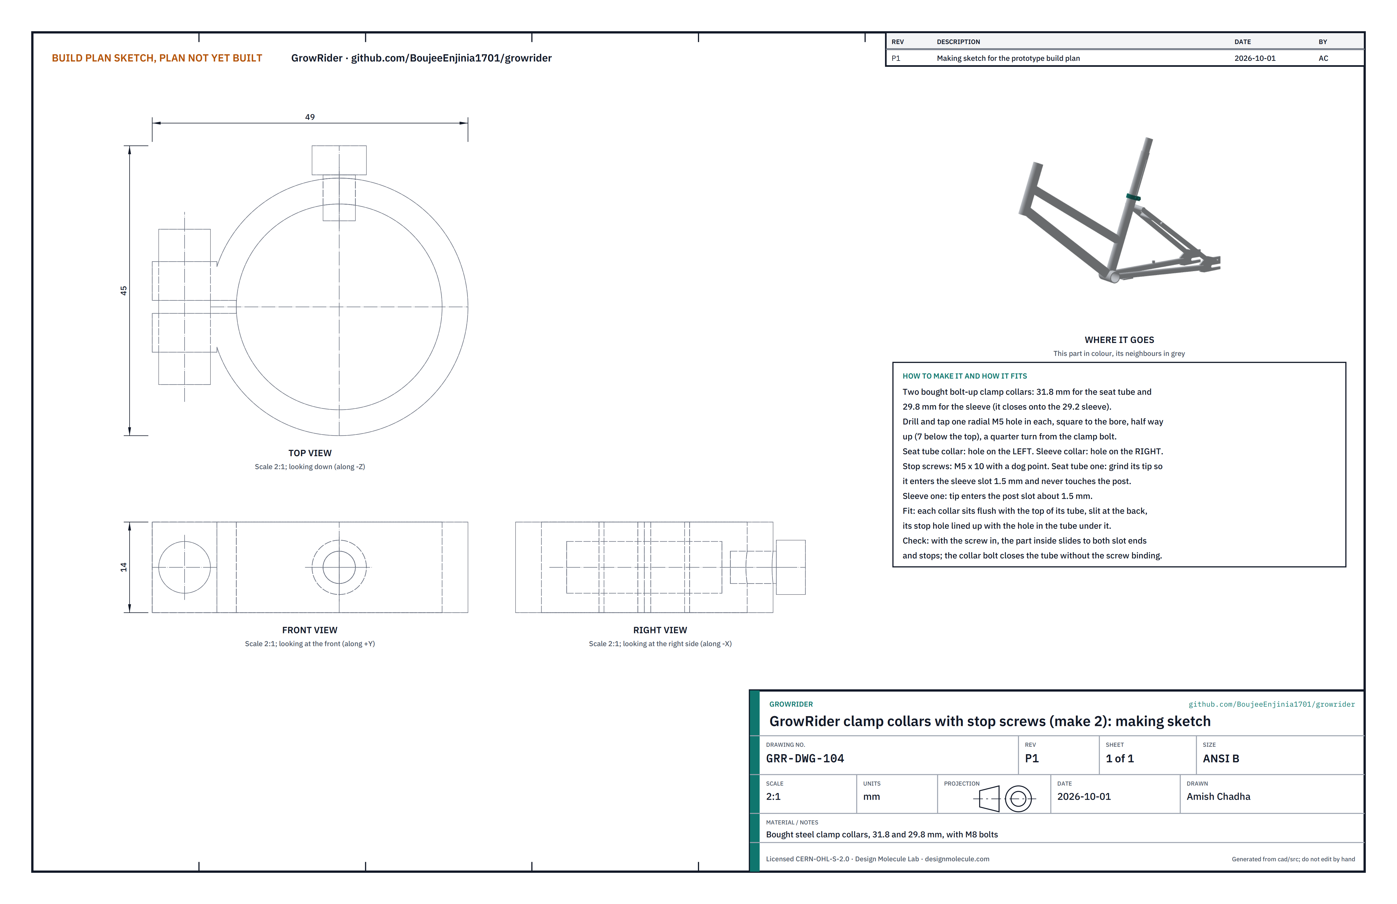
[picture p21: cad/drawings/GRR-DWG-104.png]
Figure 9. Making sketch of the clamp collars


*Figure 9. Clamp collar making sketch (GRR-DWG-104); the seat tube collar is drawn, the sleeve collar is the same at its own size.*

**What it is and what it is made from.** The bolt-up collars that lock each sliding stage, each carrying the stop screw for the part inside. Two bought steel clamp collars with 13 mm (M8) bolts: 31.8 for the seat tube and 29.8 for the sleeve. Two M5 x 10 dog-point screws.

**How to make it.**

1. On each collar, mark a point half way up, a quarter turn from the clamp bolt.
2. Drill 4.2 square to the bore and tap M5.
3. Seat tube collar: the hole is on the left. Sleeve collar: the hole is on the right.
4. Grind the seat tube collar's screw so its tip enters the sleeve slot 1.5 and never reaches the post (the sleeve wall is 1.8 thick). Grind the sleeve collar's screw so its tip enters the post slot about 1.5.

**How it fits the parts next to it.**

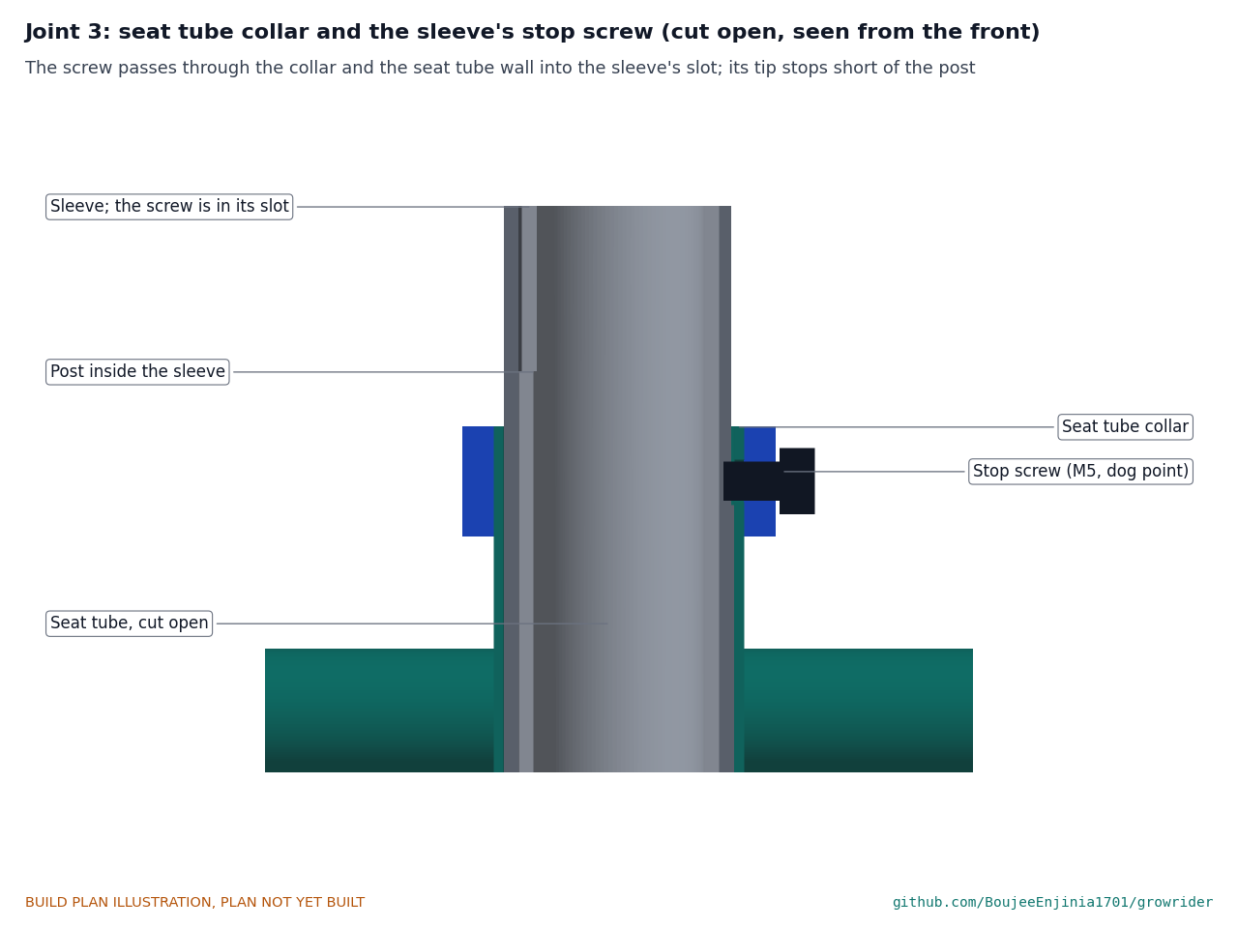
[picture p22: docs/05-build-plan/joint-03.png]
Figure 10. Joint 3: seat tube collar and the sleeve's stop screw


*Figure 10. Cut open across the bike and seen from the front: the screw passes through the collar and the seat tube wall into the sleeve's slot, and its tip stops 0.6 short of the post.*

Each collar sits flush with the top of its tube, its slit over the tube's slit at the back, its hole lined up with the hole in the tube.

**Check before moving on.** With the screw in, the part inside slides from one slot end to the other and stops at each; the collar bolt closes the tube without the screw binding.

### 3.5 Seat post, slotted

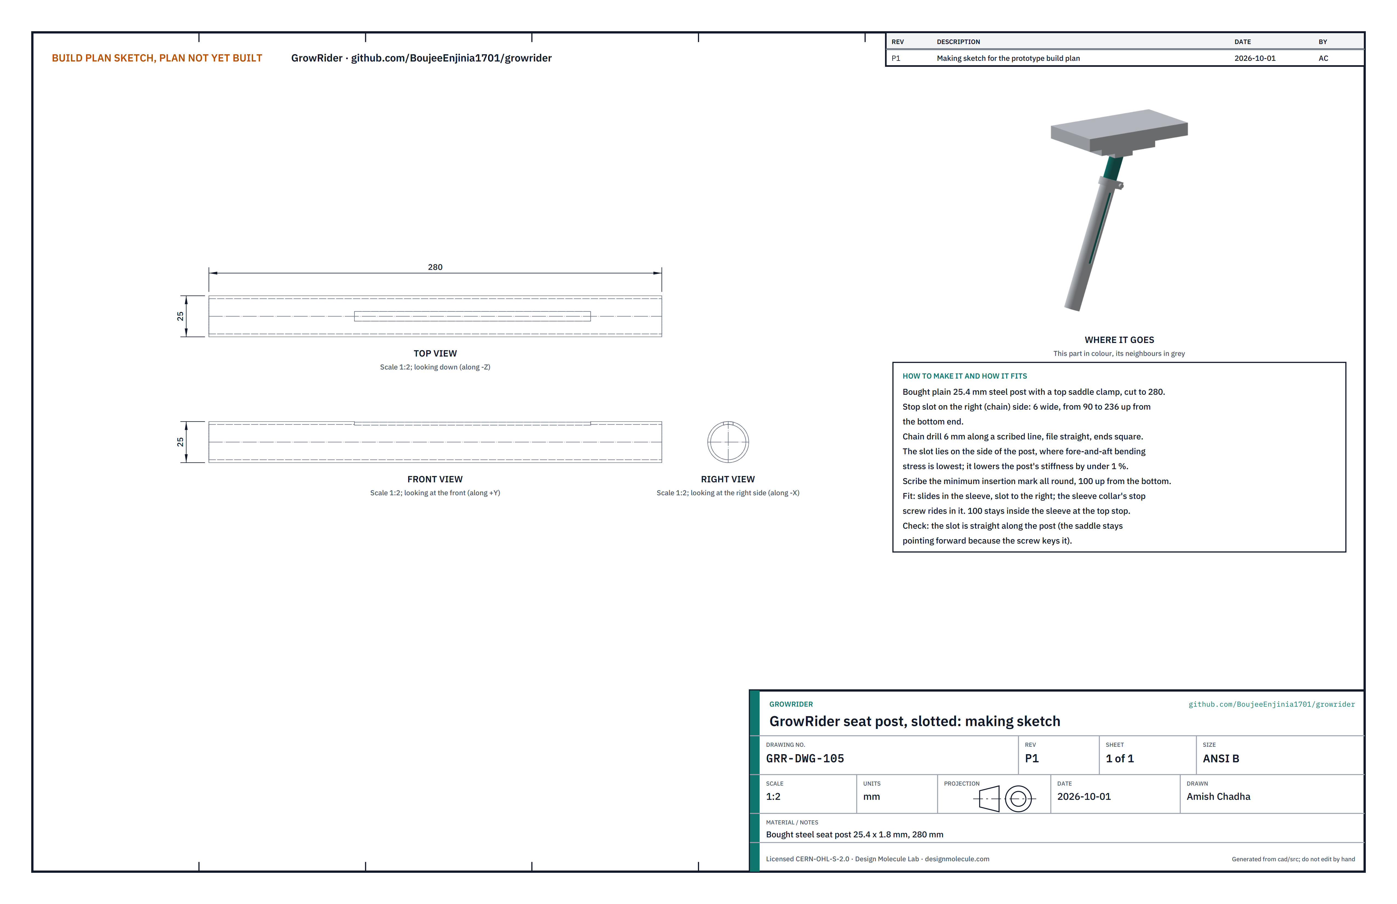
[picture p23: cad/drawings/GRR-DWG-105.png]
Figure 11. Making sketch of the seat post


*Figure 11. Seat post making sketch (GRR-DWG-105), drawn lying down with its slot facing up.*

**What it is and what it is made from.** The second sliding stage, carrying the saddle. A bought plain 25.4 steel seat post with a top saddle clamp, 1.8 wall, cut to 280 long.

**How to make it.**

1. Cut to 280 if longer; deburr the bottom end.
2. On the right side, scribe a line along the post and mark a slot 6 wide from 90 to 236 up from the bottom end.
3. Chain drill and file as for the sleeve, ends square. The slot is on the side, where fore-and-aft bending stress is lowest; it lowers the post's stiffness by under 1 %.
4. Scribe the minimum insertion mark all the way round, 100 up from the bottom end.

**How it fits the parts next to it.**

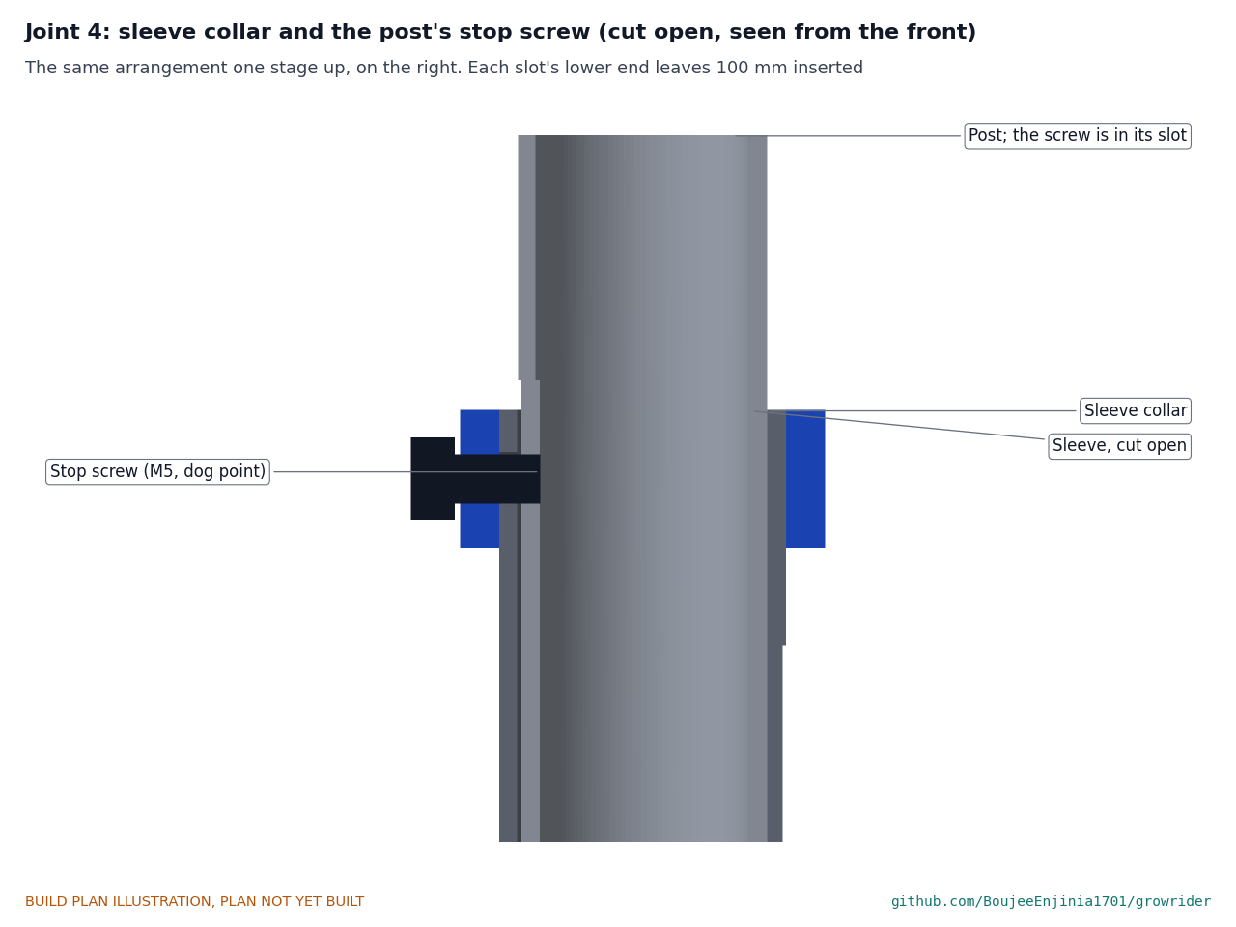
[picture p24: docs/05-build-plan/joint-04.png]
Figure 12. Joint 4: sleeve collar and the post's stop screw


*Figure 12. The same arrangement one stage up, on the right: the sleeve collar's screw rides in the post's slot.*

The post slides in the sleeve, slot to the right, with 0.2 clearance on the diameter. The screw also keys the post so the saddle stays pointing forward.

**Check before moving on.** The slot is straight along the post; the post slides in the sleeve from stop to stop.

### 3.6 Quill stem with head plate

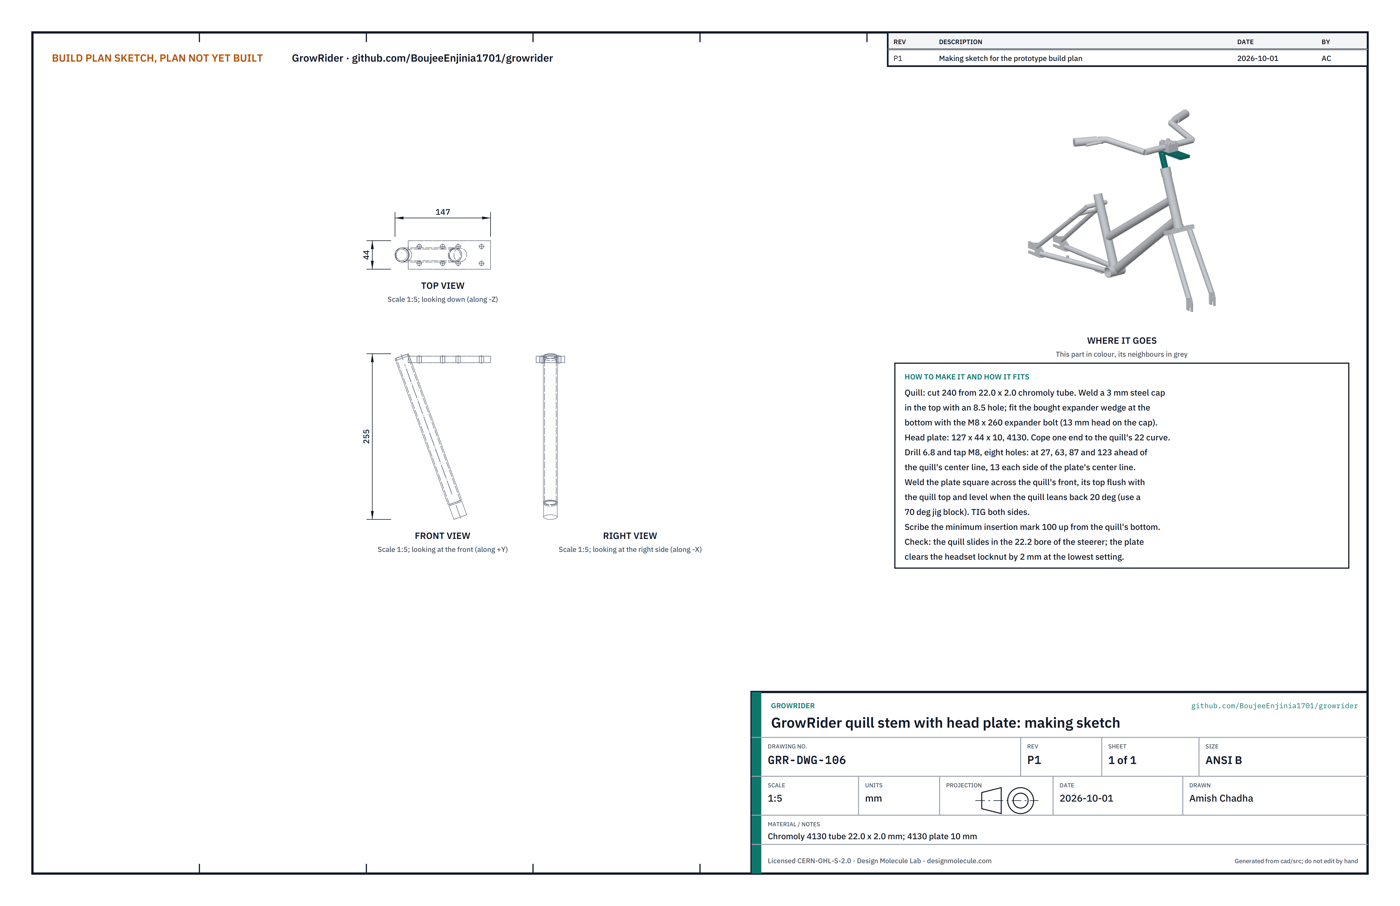
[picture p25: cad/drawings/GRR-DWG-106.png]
Figure 13. Making sketch of the quill stem


*Figure 13. Quill stem making sketch (GRR-DWG-106).*

**What it is and what it is made from.** The sliding stem that sets handlebar height: a tube in the fork's steerer, locked by an expander wedge, with a flat plate on top that carries the bar clamp. Chromoly 4130 tube 22.0 x 2.0, 240 long; 4130 plate 10 thick, 127 x 44; a 3 mm steel cap; a bought quill expander wedge and an M8 x 260 expander bolt with a 13 mm head.

**How to make it.**

1. Cut the quill 240 long. Cut the bottom end at the angle of your wedge (most are 45°).
2. Weld the cap into the top end and drill it 8.5 for the expander bolt.
3. Cut the plate to 127 x 44. File one end to the quill's 22 curve so it sits snug against the quill's front.
4. Drill 6.8 and tap M8, eight holes: at 27, 63, 87 and 123 ahead of the quill's center line, each 13 each side of the plate's center line. The first four are the back bar position, the last four the front.
5. Hold the quill leaning back 20° from upright (a 70° block on the welding table) and the plate level across its front, the plate's top flush with the quill's top. TIG weld both sides of the joint.
6. Fit the wedge and expander bolt. Scribe the minimum insertion mark all the way round, 100 up from the quill's bottom.
7. Paint a bright band all the way round just above the mark, so a quill set close to its limit is easy to see. Above the band, paint a height scale like the sleeve's: a band every 20 mm and a longer band every 60 mm.

**How it fits the parts next to it.**

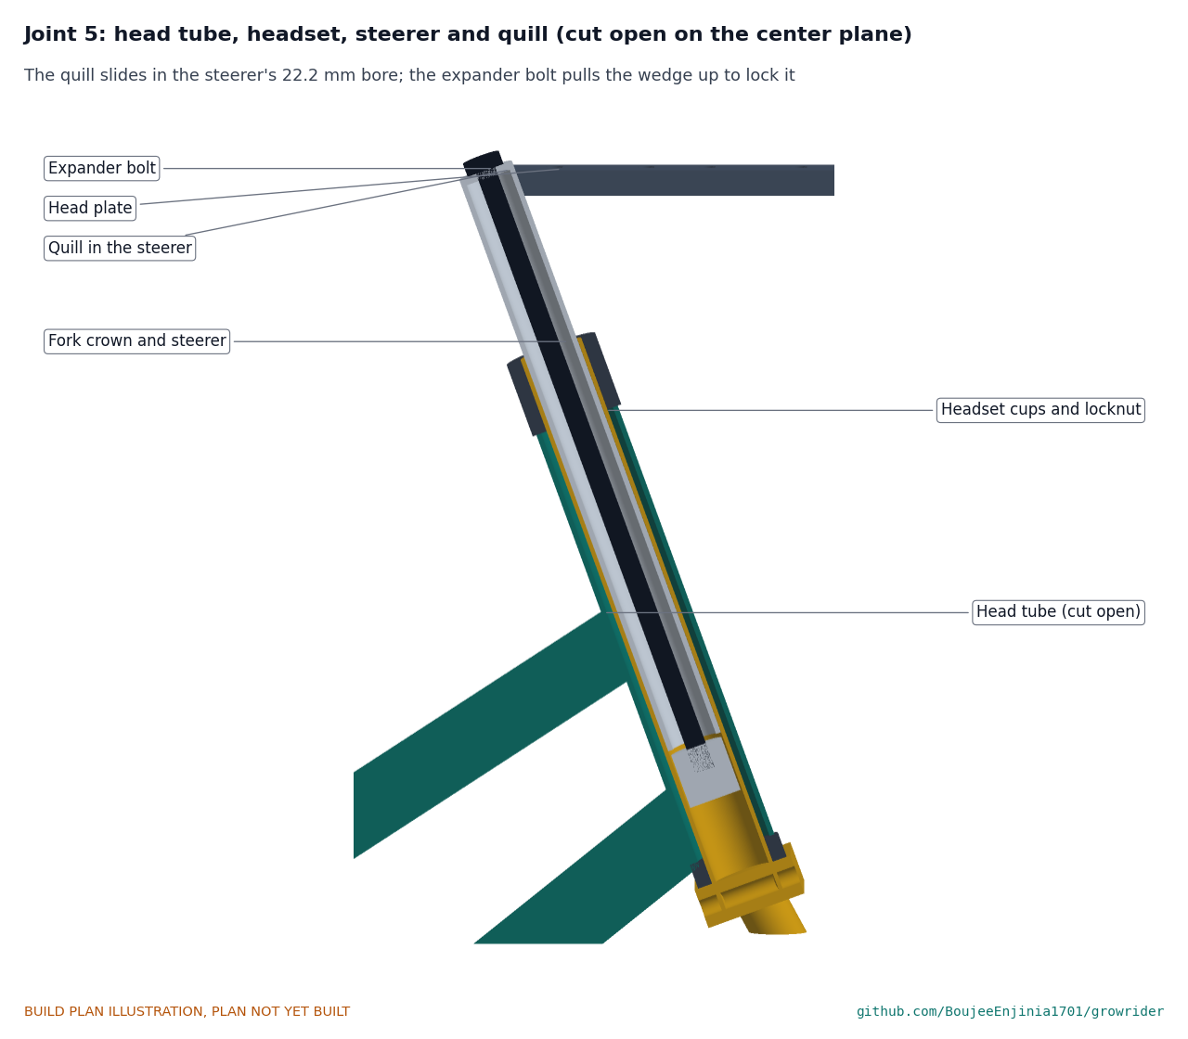
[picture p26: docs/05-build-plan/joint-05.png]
Figure 14. Joint 5: head tube, headset, steerer and quill


*Figure 14. Cut open on the center plane: the quill slides in the steerer's 22.2 bore; the expander bolt pulls the wedge up to lock it.*

The quill slides in the steerer with 0.2 clearance on the diameter. At the lowest setting the quill top stands 20 above the headset locknut and the plate clears the locknut by 2. The quill has no stop screw: the minimum insertion mark is the only limit, so it must always be inside the steerer; the bright band above it catches the eye when the quill is near its limit (safety stop S4).

**Check before moving on.** The quill slides the full 120 of travel; the plate is level when the quill is in the steerer.

### 3.7 Bar clamp block

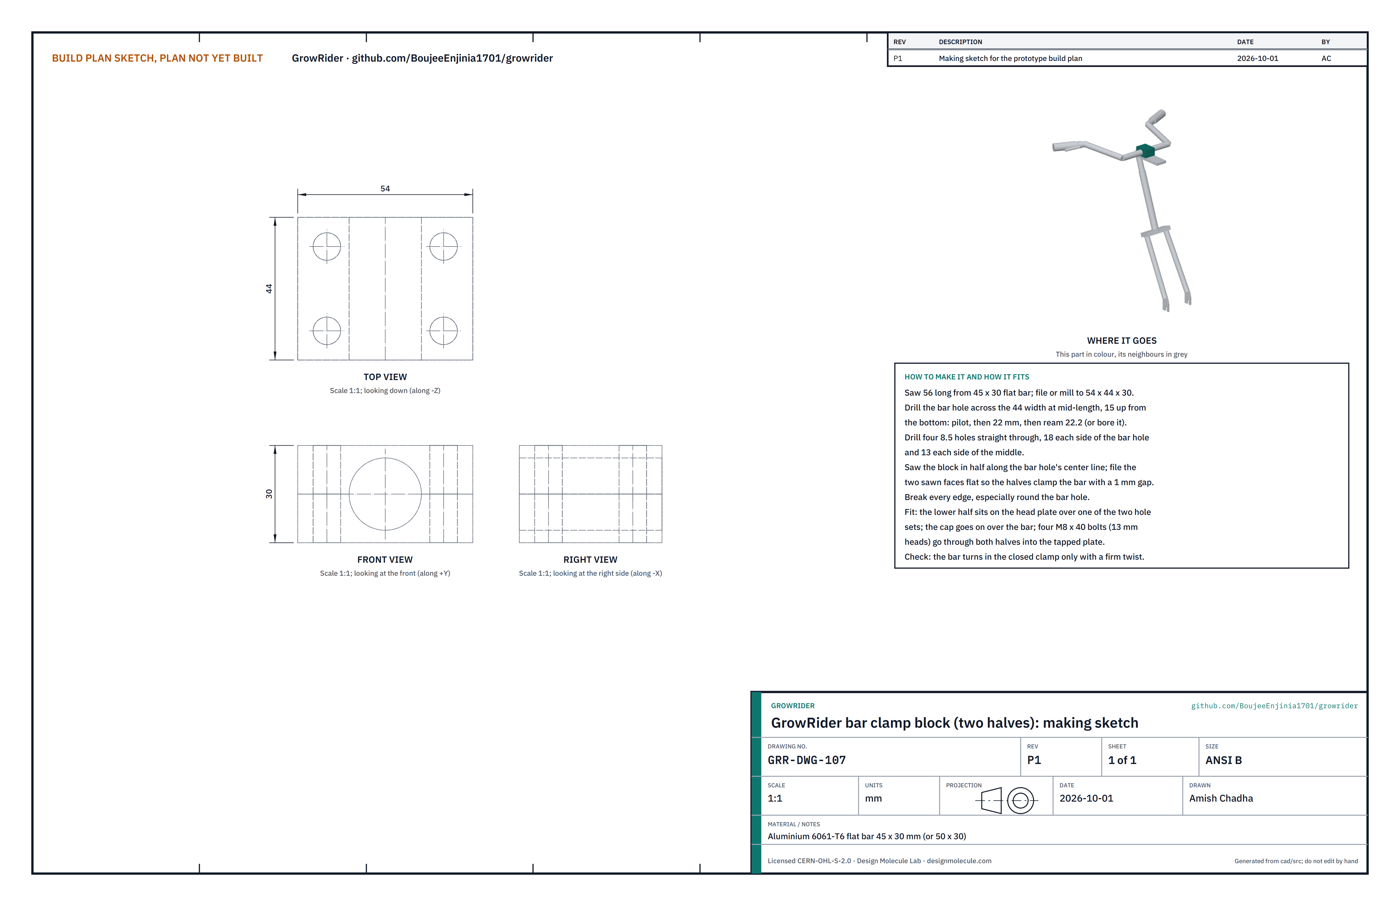
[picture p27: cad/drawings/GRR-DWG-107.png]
Figure 15. Making sketch of the bar clamp block


*Figure 15. Bar clamp block making sketch (GRR-DWG-107).*

**What it is and what it is made from.** The two-piece block that clamps the handlebar to the head plate. Aluminium 6061-T6 flat bar 45 x 30 (or 50 x 30); four M8 x 40 bolts with 13 mm heads.

**How to make it.**

1. Saw a 56 long piece and file or mill it square to 54 x 44 x 30.
2. Across the 44 width, at mid-length and 15 up from the bottom, drill a pilot, then 22, then ream 22.2 (or bore it on a lathe).
3. Drill four 8.5 holes straight through, 18 each side of the bar hole and 13 each side of the middle.
4. Saw the block in half through the bar hole's center line and file the sawn faces flat, so the closed halves leave about a 1 gap and grip the bar.
5. Break every edge, especially round the bar hole.

**How it fits the parts next to it.**

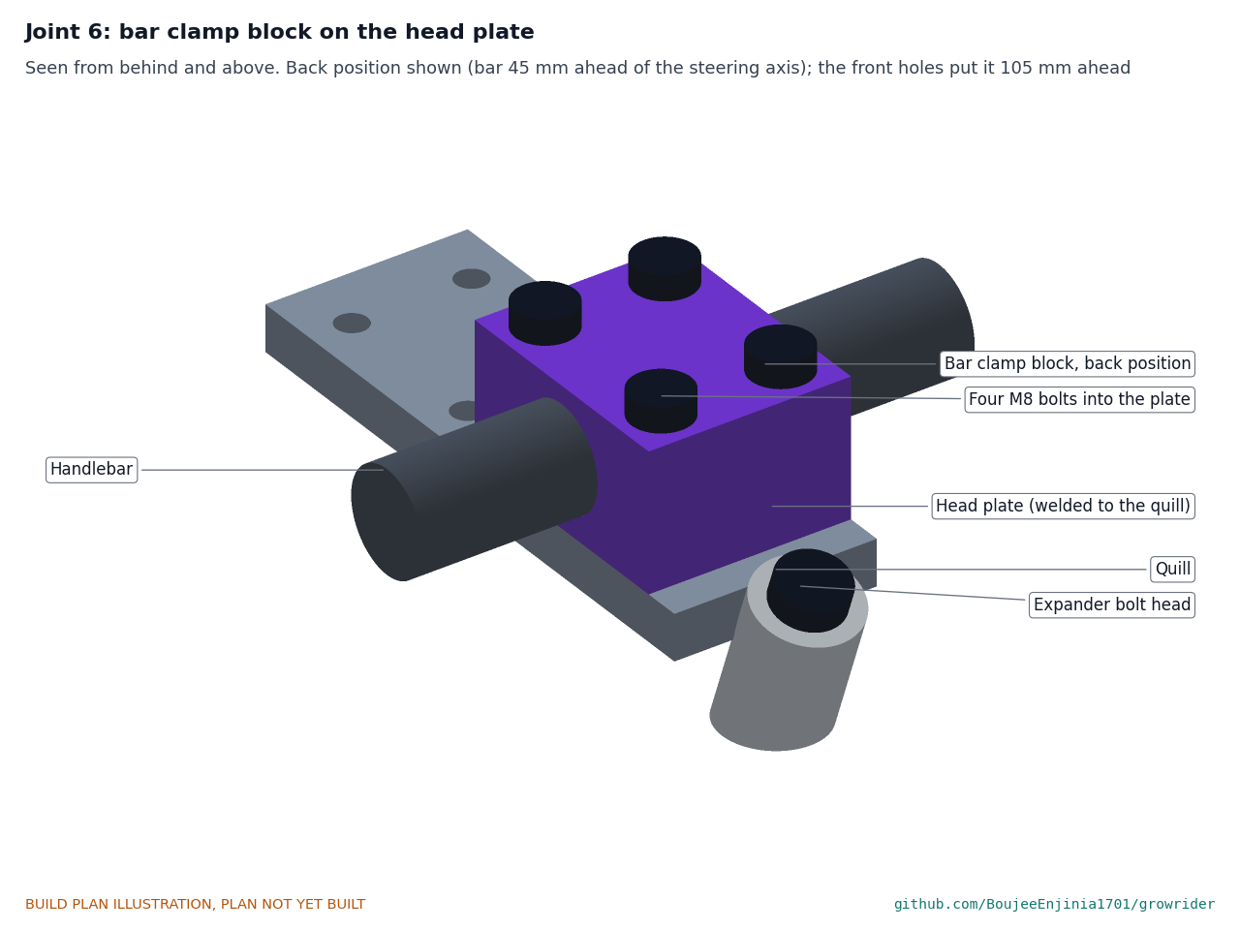
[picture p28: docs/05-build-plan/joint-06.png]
Figure 16. Joint 6: bar clamp block on the head plate


*Figure 16. The lower half sits on the head plate over one set of holes; the cap goes over the bar; four bolts pass through both halves into the tapped plate.*

In the back position the bar is 45 ahead of the steering axis, in the front position 105. Moving between them takes the four bolts and a 13 mm spanner. The expander bolt head stays clear for a socket in both positions.

**Check before moving on.** With the bolts tight the bar turns in the clamp only with a firm twist.

### 3.8 Rack

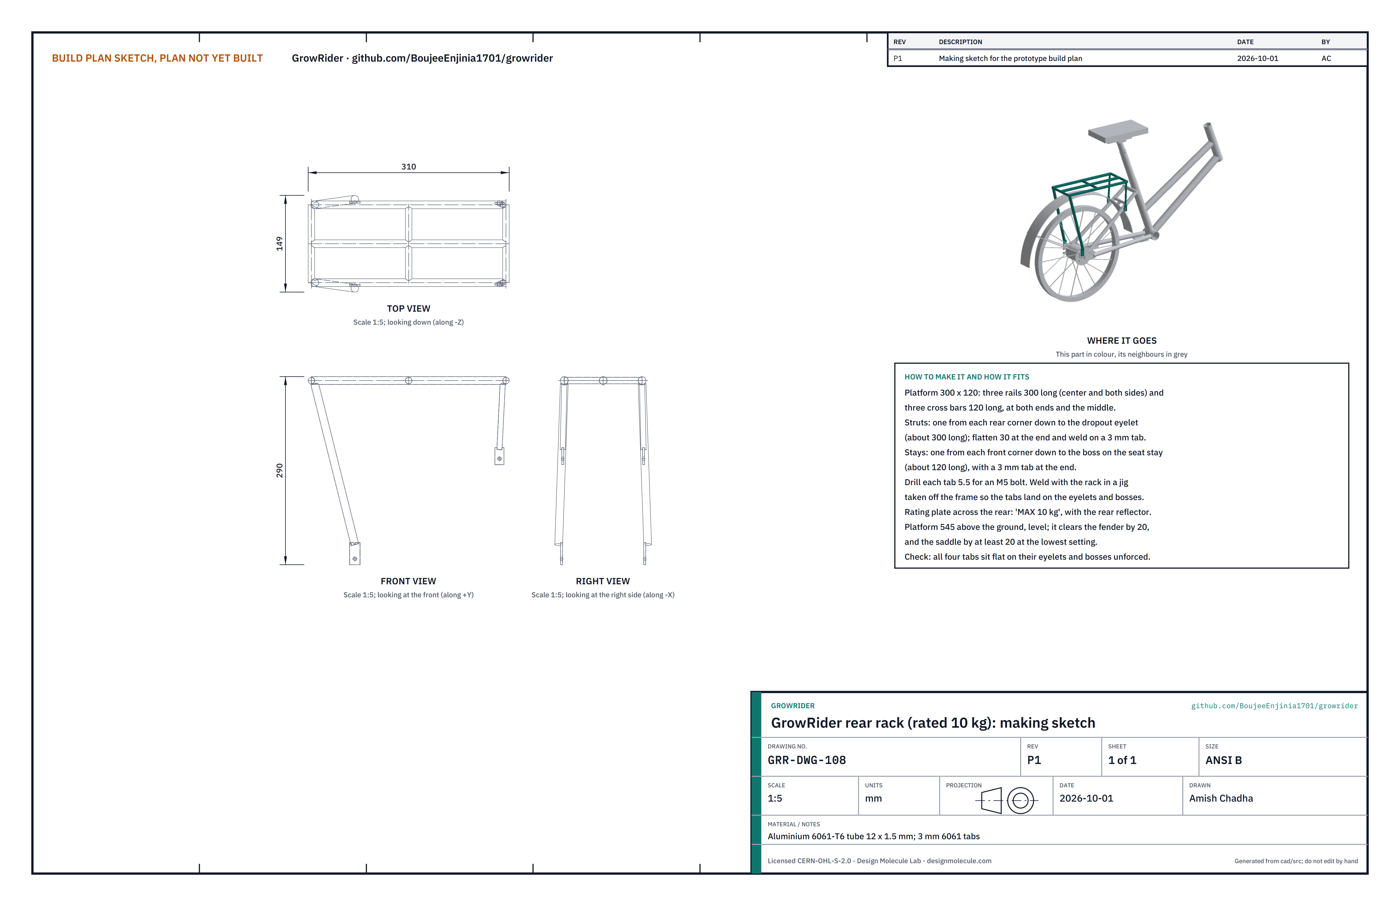
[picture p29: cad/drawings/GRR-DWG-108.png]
Figure 17. Making sketch of the rack


*Figure 17. Rack making sketch (GRR-DWG-108).*

**What it is and what it is made from.** The small rear platform for a school bag, rated 10 kg. Aluminium 6061-T6 tube 12 x 1.5; 3 mm aluminium tabs; a rating plate.

**How to make it.**

1. Platform: three rails 300 long (the middle one and one each side, 60 from the middle) and three cross bars 120 long at both ends and the middle. Weld in a flat jig.
2. Struts: one from each rear corner down to a dropout eyelet, about 300 long. Flatten 30 at the lower end and weld on a 3 mm tab drilled 5.5.
3. Stays: one from each front corner down to the boss on each seat stay, about 120 long, with a drilled 3 mm tab at the end.
4. Weld the struts and stays with the rack in a jig taken off the frame, so the tabs land on the eyelets and bosses unforced.
5. Fix the rating plate across the rear, marked "MAX 10 kg", with the rear reflector.

**How it fits the parts next to it.** The struts' tabs go on the outside of the dropout eyelets, over the fender stay eyes (Figure 3); the stays' tabs go on the seat stay bosses (Figure 6). Four M5 bolts. The platform sits level, 545 above the ground; it clears the fender by 20 and the saddle by 37 at the lowest saddle setting.

**Check before moving on.** All four tabs sit flat on their eyelets and bosses with the bolts in by hand.

### 3.9 Bought components

Buy to specification, not brand. Line numbers are those of the bill of materials.

- **Fork (line 2).** 20 in (ISO 406), 30 mm offset, crown no deeper than 16, a 1 in threaded chromoly steerer 25.4 x 1.6 (22.2 bore) with 220 usable above the crown, slotted fork ends 100 apart with M5 eyelets, a hole through the crown for the caliper bolt. Cut and thread the steerer to suit the head tube if needed.
- **Headset and bottom bracket (line 18).** 1 in threaded headset with 30.0 press-in cups and a 32 mm locknut; cup-and-cone or cartridge bottom bracket for a 68 mm BSA shell.
- **Wheels (lines 7 and 8).** 20 in (ISO 406) alloy rims. Front: 28 spokes, 100 between locknuts, 3/8 in nutted axle. Rear: 36 spokes, single-speed coaster brake hub 110 between locknuts, 18T sprocket on a 42 chain line, with its brake arm.
- **Arm clip (line 19).** A coaster brake arm clip for a 19 mm chainstay, with an M6 bolt.

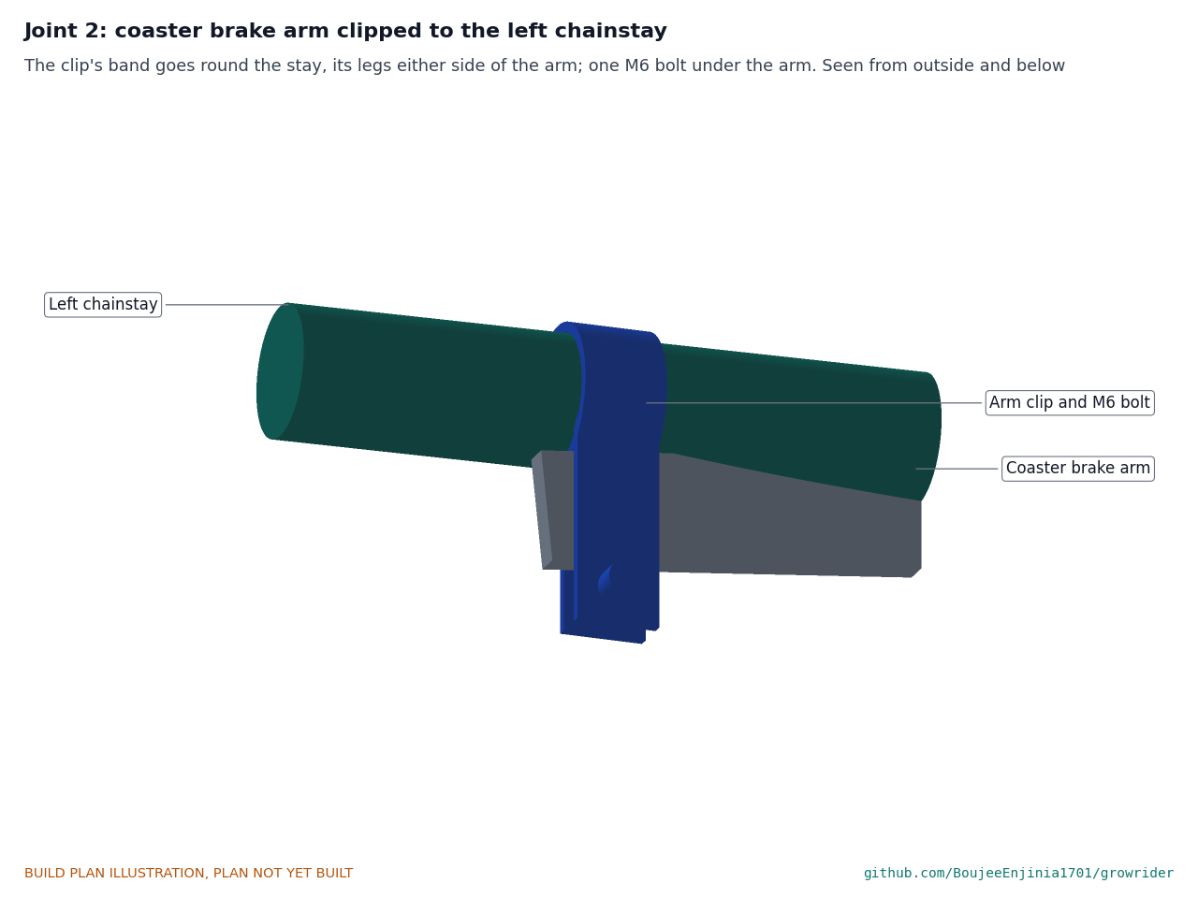
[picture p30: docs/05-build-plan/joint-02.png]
Figure 18. Joint 2: coaster brake arm clipped to the left chainstay


*Figure 18. The clip's band goes round the chainstay and its legs either side of the arm; one M6 bolt under the arm takes the braking force.*

- **Tires (line 9).** Two 20 x 1.95 in solid or airless tires, no wider than 50 on the rim.
- **Crankset and pedals (line 10).** 140 mm steel cranks, 32T chainring on a 42 chain line, 9/16 in pedal threads, reflective pedals.
- **Chain (line 11).** 1/2 x 1/8 in single-speed chain, 86 links.
- **Front brake (line 12).** A long-reach side-pull caliper whose reach covers 84, on a nutted bolt; a short-reach child's lever with reach adjustment; cable and housing with slack for 120 of stem travel.

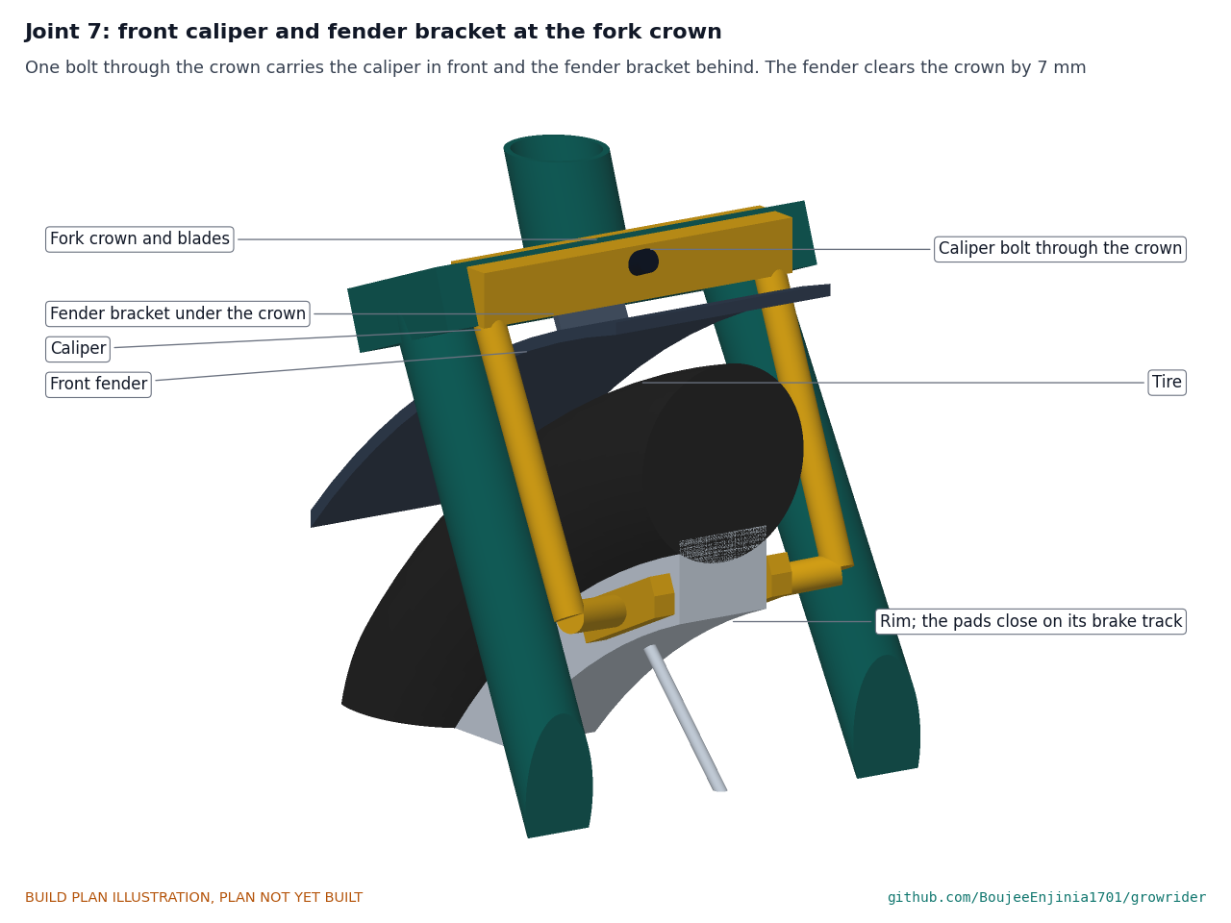
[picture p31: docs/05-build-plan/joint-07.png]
Figure 19. Joint 7: front caliper and fender bracket at the fork crown


*Figure 19. One bolt through the crown carries the caliper in front and the front fender bracket behind; the fender clears the crown by 7.*

- **Saddle (line 4), handlebar and grips (line 6).** Child-size saddle with a standard rail clamp. 22.2 alloy roadster-style bar, 520 wide, about 205 sweep and 15 rise; rubber grips.
- **Fenders (line 14).** Plastic, 20 in, 64 wide, with wire stays and L brackets. Trim the rear fender's front end to start 10° above the axle line.
- **Chainguard (line 15).** Plate guard for the upper chain run, with a seat tube clip and a tab for the chainstay boss. The name "GrowRider" is screen printed on its outer face.
- **Kickstand (line 16).** Centre-mount kickstand with its clamp plate and an M10 bolt.
- **Reflectors and bell (line 17).** Front white, rear red, two spoke reflectors per wheel, bell.
- **Fixings (line 19).** M8 collar bolts; M5 bolts with nyloc nuts for the rack, fender stays and chainguard; grease; warning labels for the minimum insertion marks.

## 4. Putting it together

In each picture the parts already fitted are grey and the part being fitted is in colour, with an arrow showing the way it goes in. Grease every thread and every sliding surface.

### Step 1: bottom bracket into the frame

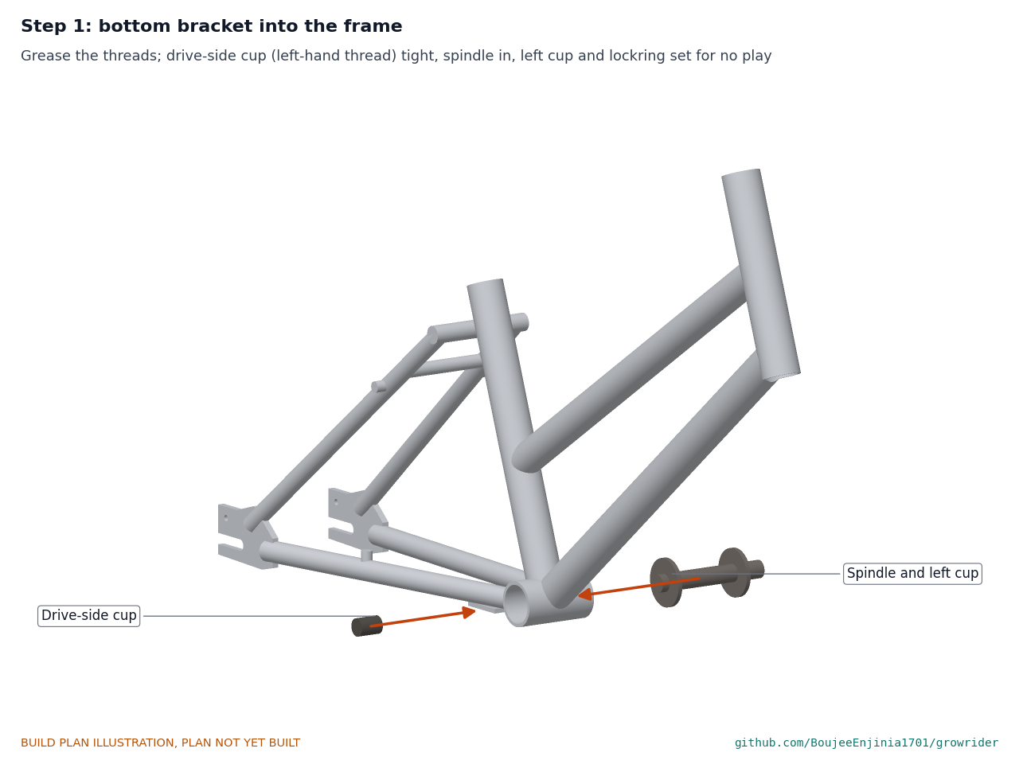
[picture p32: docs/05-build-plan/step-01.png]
Step 1


Right-hand (drive side) cup in first; it has a left-hand thread. Tighten it fully. Spindle in, then the left cup and lockring, set so the spindle turns freely with no play.

### Step 2: headset cups and fork

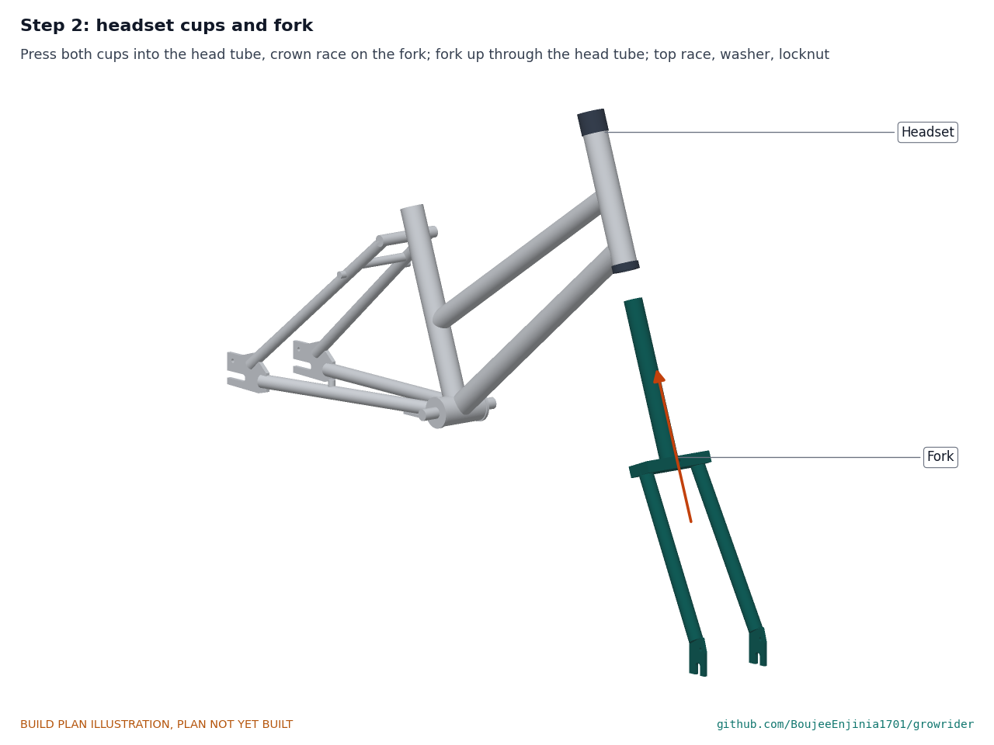
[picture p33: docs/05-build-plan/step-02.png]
Step 2


Press both cups into the head tube with a headset press or a threaded rod and washers. Fit the crown race on the fork. Fork up through the head tube; top bearing, top cup, keyed washer and locknut. Set so the fork turns freely with no play, then lock with the 32 mm spanner.

### Step 3: sleeve into the seat tube, collar and stop screw

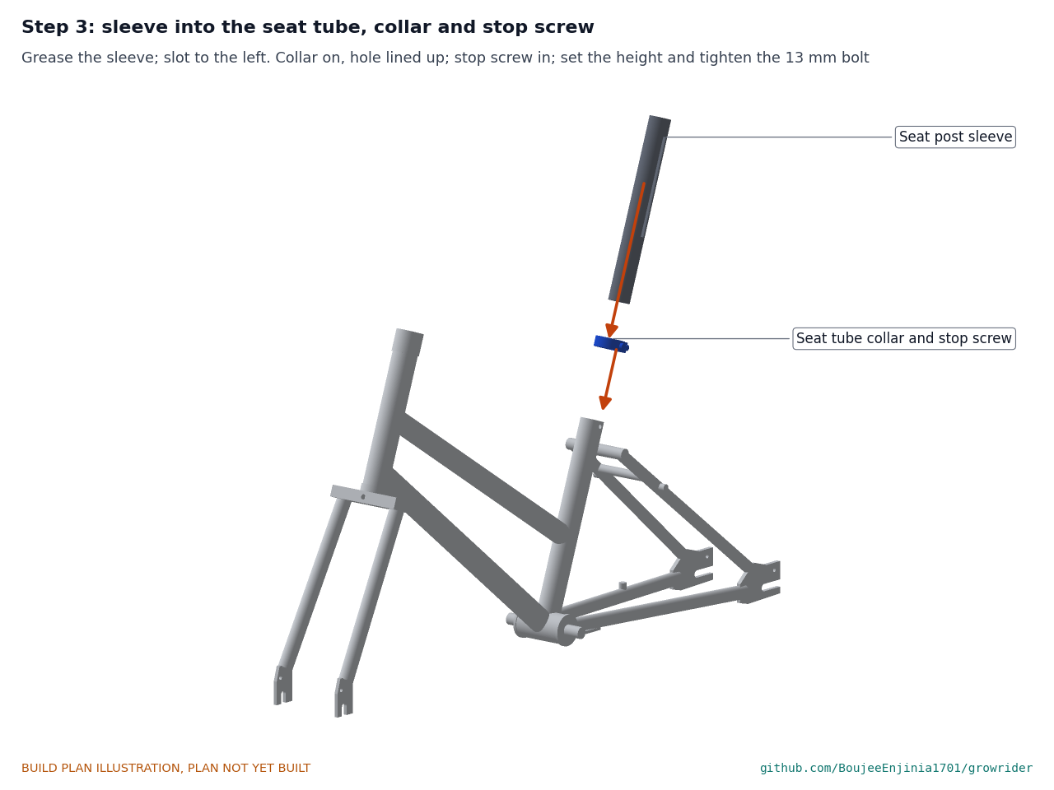
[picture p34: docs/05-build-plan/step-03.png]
Step 3


Sleeve in with its slot to the left. Collar on, flush with the top of the seat tube, its hole over the hole in the tube. Stop screw in. Set the sleeve height and tighten the 13 mm collar bolt. **Hold point:** pull the sleeve up; it must stop with its minimum insertion mark still inside the seat tube.

### Step 4: seat post, sleeve collar and saddle

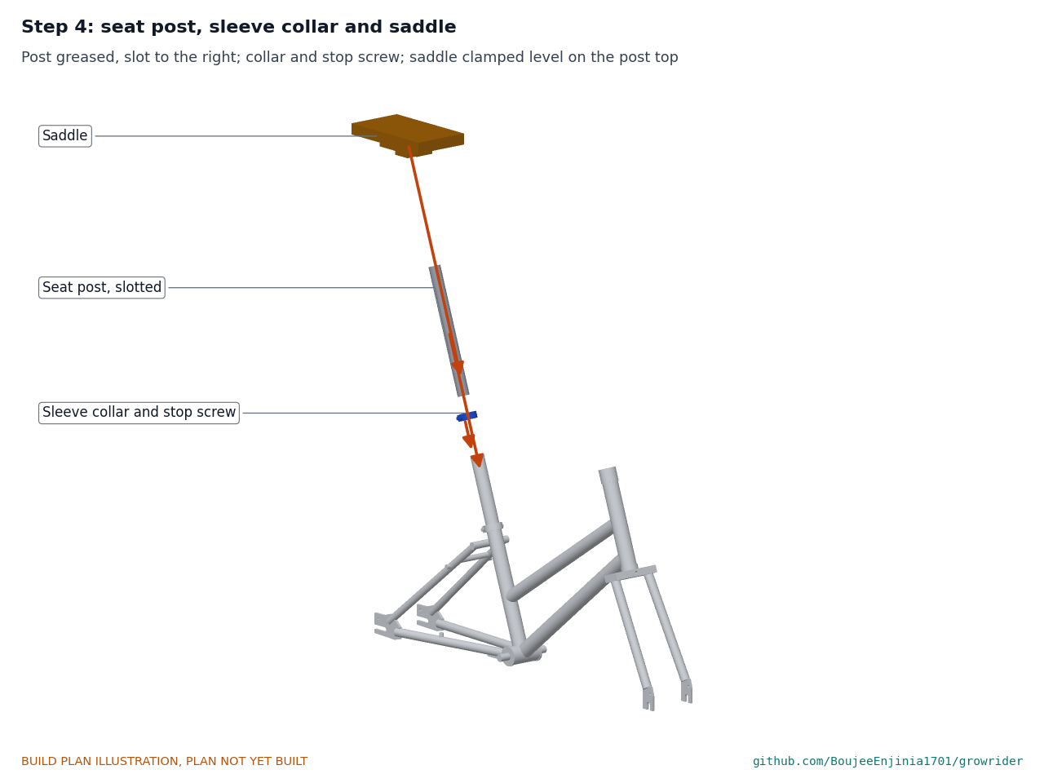
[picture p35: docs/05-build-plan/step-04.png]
Step 4


Post in with its slot to the right. Sleeve collar on, flush with the sleeve top, and its stop screw in. Saddle clamped level on the post. **Hold point:** pull the post up; it must stop with its mark inside the sleeve.

### Step 5: quill stem into the steerer

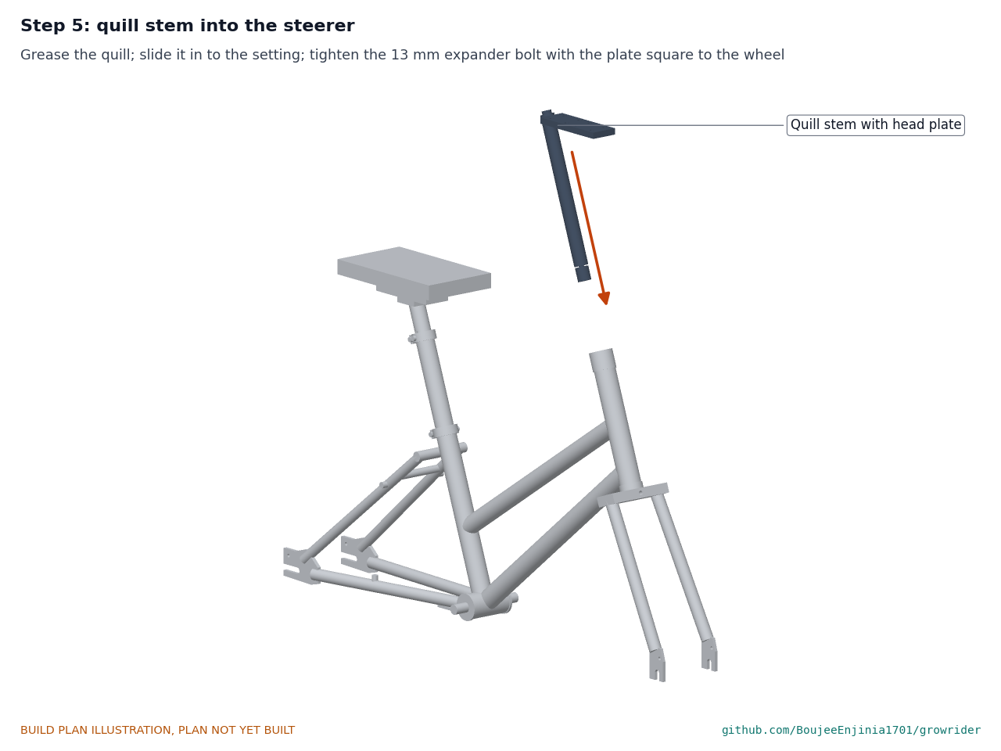
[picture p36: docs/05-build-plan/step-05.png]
Step 5


Quill in to the chosen height, head plate square to the front wheel; tighten the 13 mm expander bolt. **Hold point:** the minimum insertion mark is inside the steerer (safety stop S4).

### Step 6: bar clamp block and handlebar

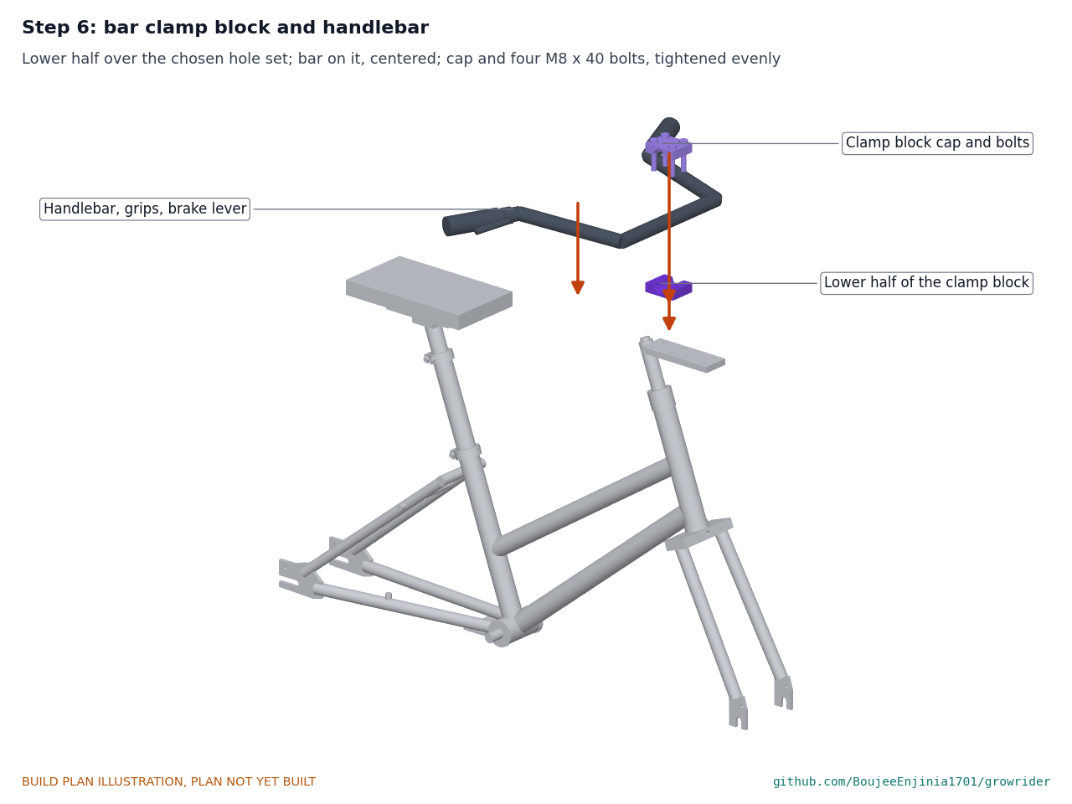
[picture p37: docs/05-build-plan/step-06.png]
Step 6


Lower half of the block on the chosen set of holes; bar on it, centered, grips level; cap on; four M8 x 40 bolts tightened evenly in a cross pattern. Fit the grips and the brake lever on the right grip.

### Step 7: front fender and caliper on the crown

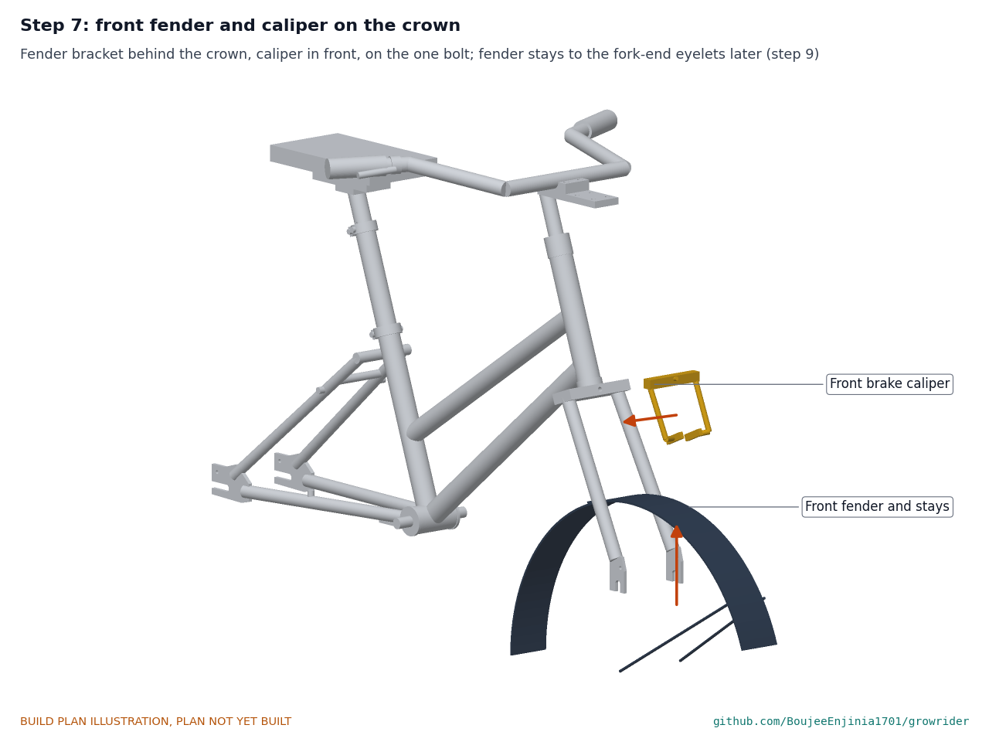
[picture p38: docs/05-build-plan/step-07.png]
Step 7


Front fender up between the fork blades, its bracket behind the crown; caliper in front; one bolt through all three, nut behind. Leave the fender stays loose until step 9.

### Step 8: tires onto the rims

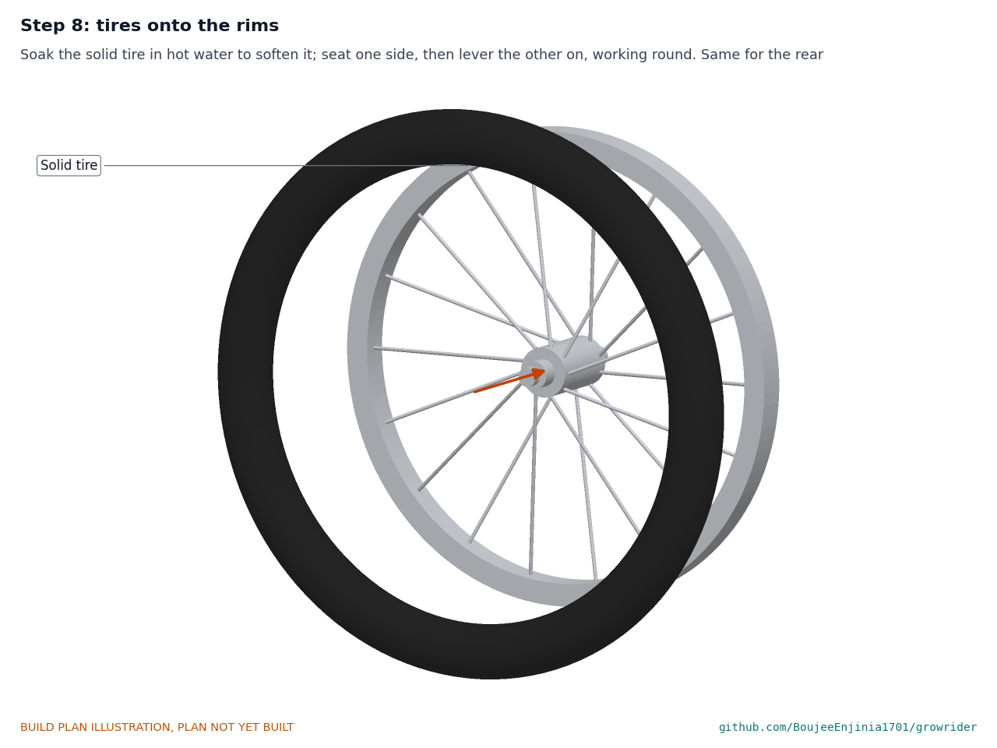
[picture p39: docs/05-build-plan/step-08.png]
Step 8


Soak each solid tire in hot water for a few minutes to soften it. Seat one side on the rim, then work the other side on with tire levers, a little at a time round the rim. Same for the rear wheel.

### Step 9: front wheel into the fork

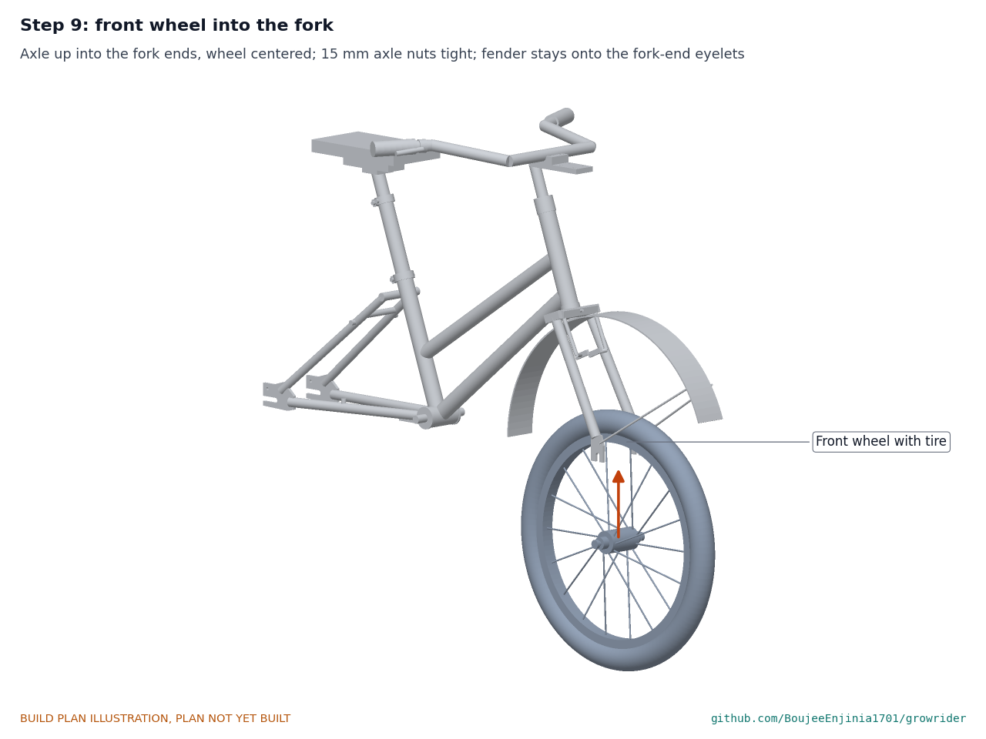
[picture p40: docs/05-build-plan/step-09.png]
Step 9


Axle up into the fork ends, wheel centered between the blades; axle nuts tight. Fender stays onto the fork-end eyelets with M5 bolts. Set the caliper pads on the rim's brake track.

### Step 10: crankset and pedals

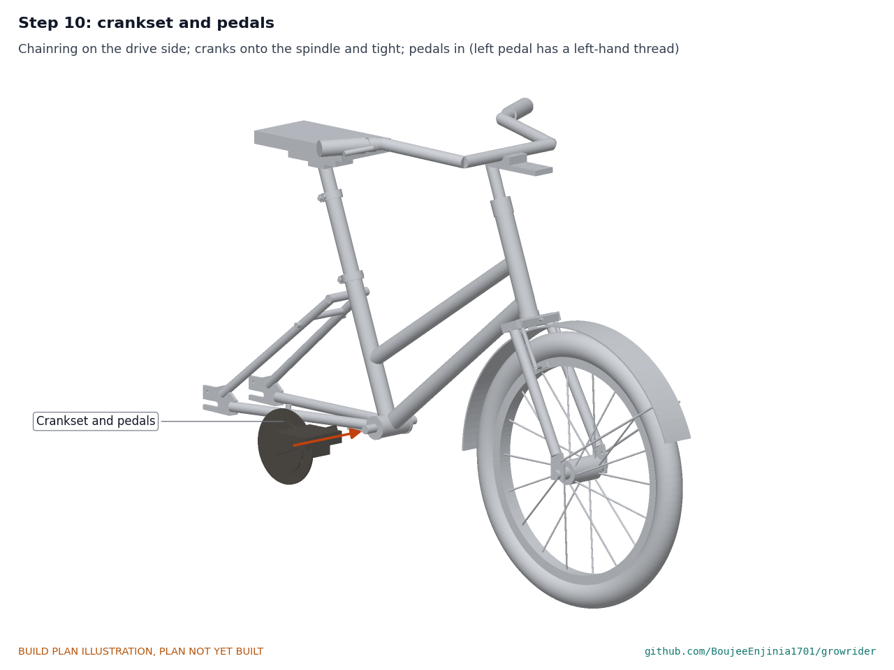
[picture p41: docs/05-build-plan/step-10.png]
Step 10


Chainring on the right. Cranks onto the spindle and tight. Pedals in; the left pedal has a left-hand thread.

### Step 11: rear wheel into the track ends

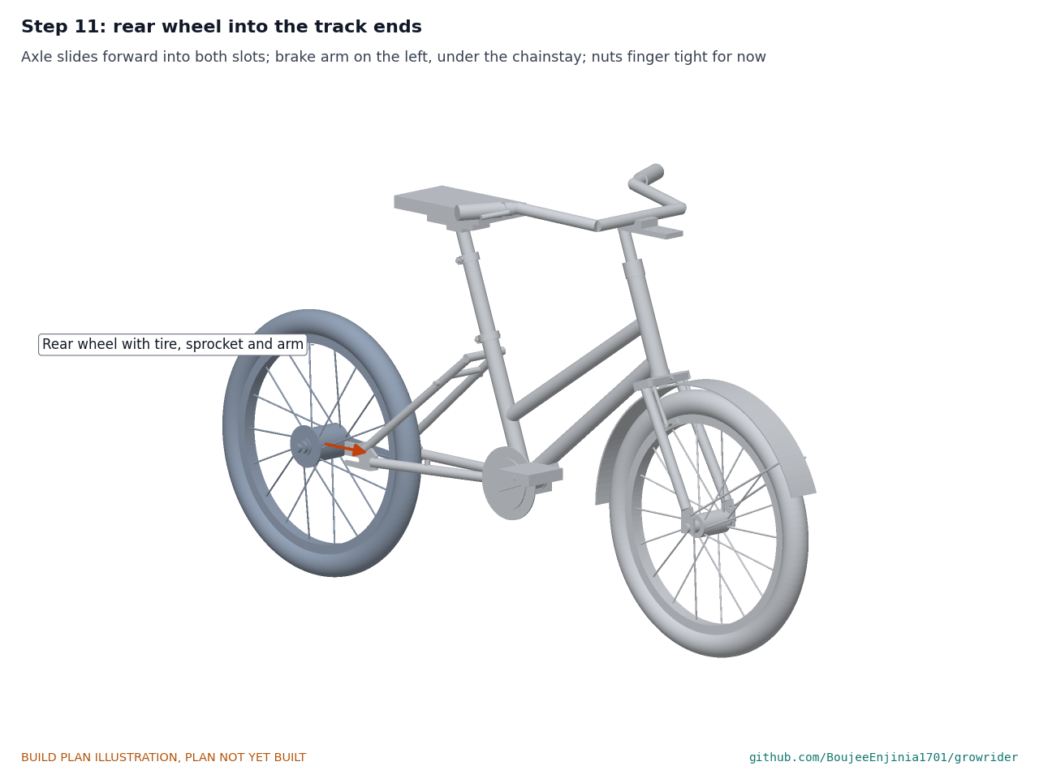
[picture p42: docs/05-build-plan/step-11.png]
Step 11


Slide the axle forward into both slots, sprocket on the right, brake arm on the left under the chainstay. Nuts finger tight for now.

### Step 12: chain, tension and brake arm clip

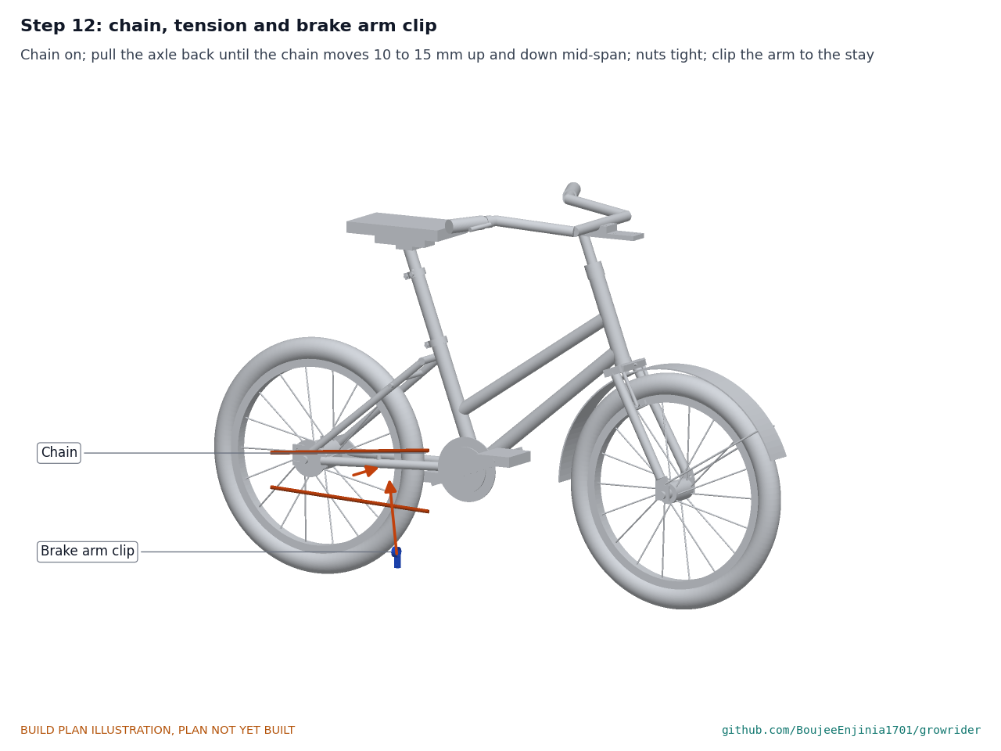
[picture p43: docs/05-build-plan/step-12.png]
Step 12


Chain on and joined. Pull the axle back until the chain moves 10 to 15 up and down half way between the sprocket and chainring, wheel centered; tighten both axle nuts. Clip the brake arm to the chainstay and tighten the M6 bolt. **Hold point:** back-pedal hard by hand; the wheel locks and the arm does not move.

### Step 13: rear fender and stays

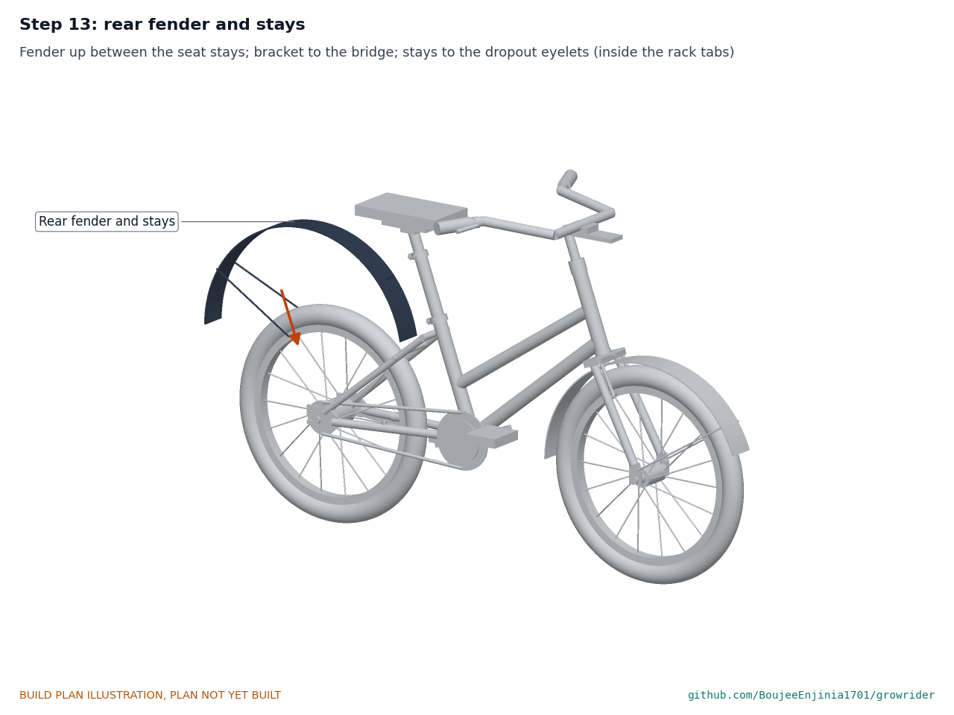
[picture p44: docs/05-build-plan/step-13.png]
Step 13


Fender up between the seat stays; its bracket bolted to the bridge; stays to the dropout eyelets, against the plates.

### Step 14: rack

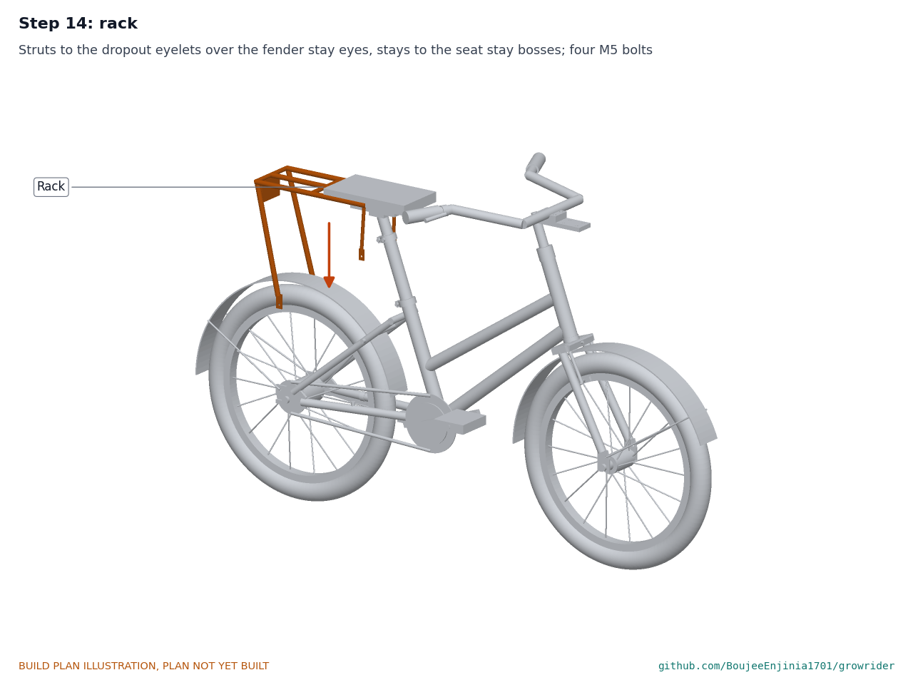
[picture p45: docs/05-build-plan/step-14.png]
Step 14


Strut tabs on the dropout eyelets over the fender stay eyes, stay tabs on the seat stay bosses; four M5 bolts with nyloc nuts.

### Step 15: chainguard

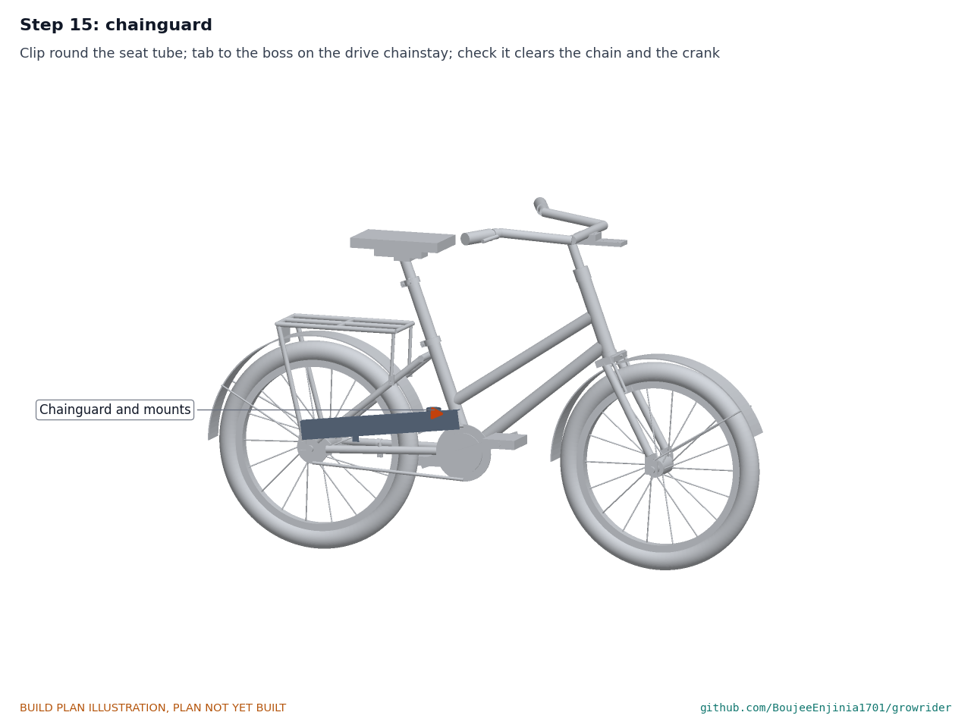
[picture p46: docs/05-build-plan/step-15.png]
Step 15


Clip round the seat tube, tab on the chainstay boss. Turn the cranks: the guard clears the chain and the crank arm.

### Step 16: kickstand

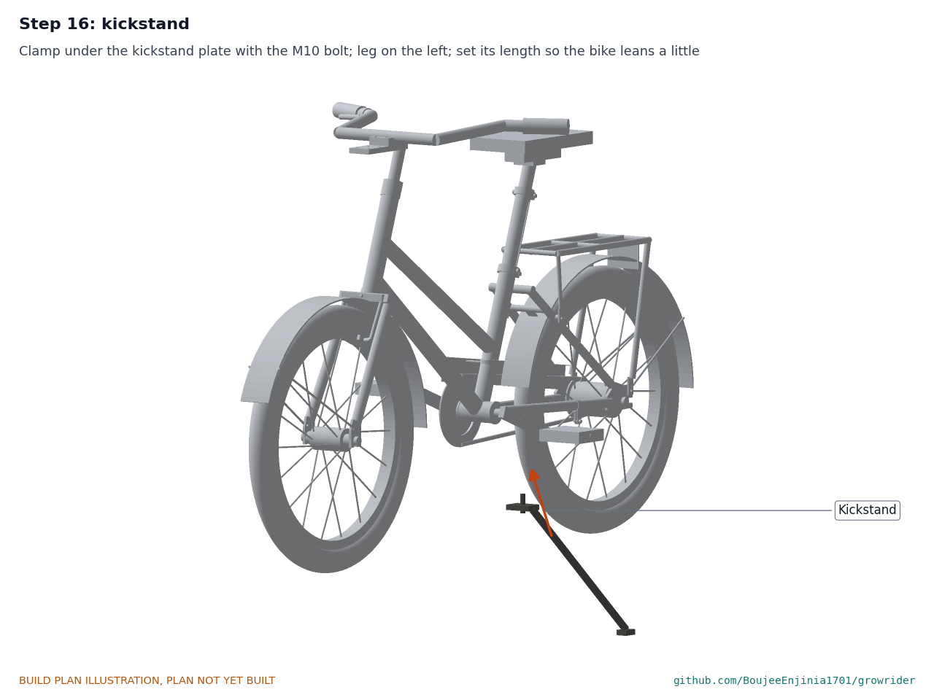
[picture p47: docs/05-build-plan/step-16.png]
Step 16


Clamp plate under the kickstand plate, leg on the left, M10 bolt tight. Cut the leg so the bike leans a little to the left when parked.

### Step 17: reflectors, bell and brake cable

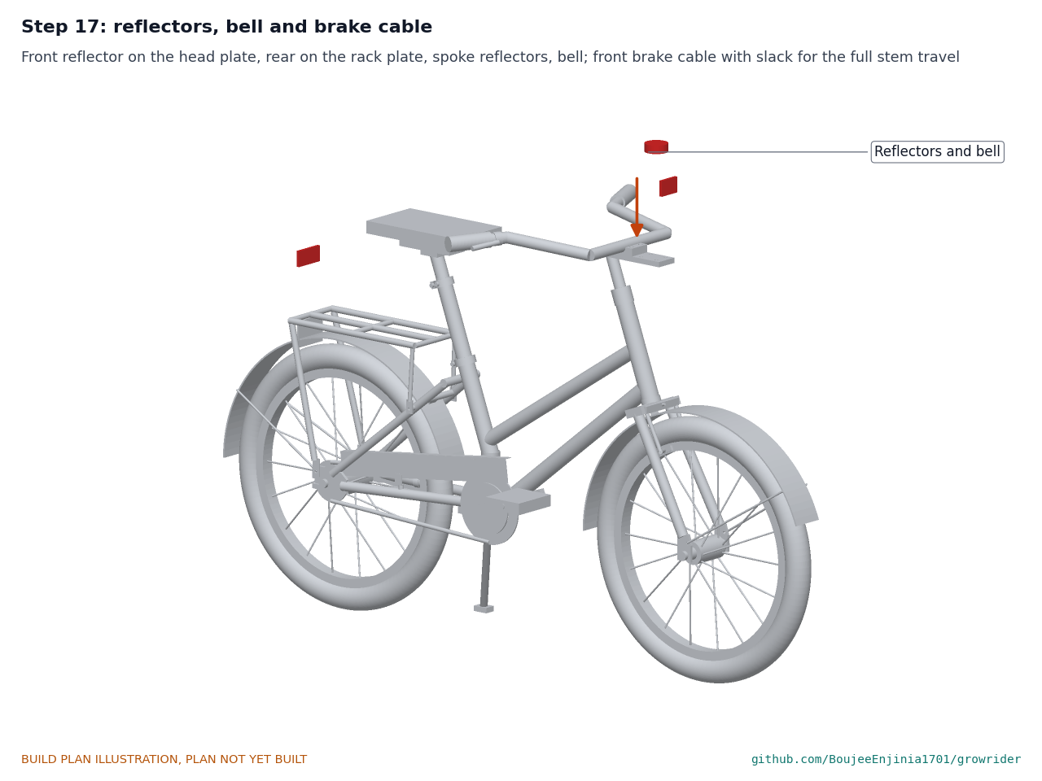
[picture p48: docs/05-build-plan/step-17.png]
Step 17


Front reflector on the front of the head plate, rear reflector on the rack plate, two spoke reflectors per wheel, bell on the bar. Run the brake cable with enough slack for the stem's full 120 of travel; set the lever reach for small hands.

## 5. First checks

These are the checks a TRL 4 test report would record; this plan only lists them. Requirement numbers are those of GRR-REQ-001. Nobody rides the bike for any of them.

*Table 2. First checks.*

| Check | Requirement | How | Pass when |
| --- | --- | --- | --- |
| Standover | R1 | Measure the loop tube's top 100 ahead of its joint with the seat tube | 470 or less above the ground (455 expected) |
| Saddle height range and stops | R2 | Set the saddle fully down, then pull each stage up to its stop; measure bottom bracket center to saddle top along the seat tube | 400 or less fully down; 670 or more at the top; every insertion mark still inside at the stops |
| Bar height and reach | R3 | Run the quill through its 120 of travel; fit the block in both positions; measure grip positions | Bar height changes by 100 or more; reach changes by 100 or more over the range |
| Wheel size | R4 | Inspect | 20 in (ISO 406) rims front and rear |
| Mass | R5 | Weigh the complete bike with rack, fenders and kickstand | Record against 13 kg (15.1 kg estimated) |
| Rack | R6 | Inspect the marking; hang 10 kg on the platform for 5 minutes, bike on its kickstand and held | Marked "MAX 10 kg"; platform 300 x 120 or less; no permanent bend |
| Brakes, on the stand | R7 | Spin each wheel by hand and brake; check the lever reach with a child's hand span | Each brake stops its wheel; pads on the brake track, clear of the tire; lever reachable at its shortest setting |
| Puncture-proof tires | R8 | Inspect | Solid or airless tires fitted, seated evenly |
| Fit change | R9 | Time a change from the smallest to the largest setting with a 13 mm spanner and a screwdriver | 10 minutes or less, no other tool |
| Stops and sliding parts | R2, R12 | Slide each stage stop to stop, ten times | No binding; each stop holds with the collar bolt loose |
| Frame alignment | R12 | String line from the dropouts to the head tube; check the rear wheel sits centered | Rear wheel centered within 2; dropouts parallel |
| Clearances | All | Turn the bar lock to lock and spin both wheels and the cranks | Nothing rubs: tire to frame 3 or more, fender to crown 5 or more, chain to frame and guard 2 or more |

## 6. Safety stops

Stop at each point. Carry on only when everything listed is true.

- **S1. Before brazing or welding.** The person brazing chromoly or TIG welding aluminium is trained for it; fume extraction is on; no galvanised or plated parts are being heated; a fire extinguisher and a metal bin for hot offcuts are at hand.
- **S2. Before the frame comes off the jig.** The frame and dropout checks of section 3.2 pass. A frame that is out of line is corrected on the jig, never by bending a brazed joint cold.
- **S3. Before any sliding part is set for a rider.** Both stop screws are in, and each stage stops with its minimum insertion mark still inside the tube below. The warning labels for the marks are on.
- **S4. At every stem setting.** The quill has no stop screw: its minimum insertion mark must be inside the steerer, below the locknut, every time the stem is set (if the bright band shows in full above the locknut, check the mark), and the expander bolt is tight.
- **S5. Before any load on the rack or the saddle.** Every bolt is tight with its nyloc nut or collar; the rack is marked "MAX 10 kg"; nothing heavier goes on it, and never a passenger.
- **S6. Before anyone rides it.** Nobody rides the prototype. The frame, fork, seat post, stem, rack and brakes must first pass the tests of ISO 4210-2, which is TRL 4 work and outside this plan.
- **S7. When fitting solid tires.** Hot water can scald and a tire lever can spring back: wear gloves and eye protection.

## 7. Tools, skills and workspace

**Tools.** Tube cutter or hacksaw; mitre files or a tube notcher; flat frame jig; brazing torch (or TIG welder) for chromoly and a TIG welder for aluminium; bench vice with soft jaws; bench drill; drills 4.2 to 12 mm and a 22 mm drill; 22.2 and 29.4 mm reamers, a 30.0 mm head tube reamer and facer, a bottom bracket tap and facer (or a frame builder's shop that has them); M5 and M8 taps; files; scriber, square, steel rule and calipers; headset press; bottom bracket tools, a 32 mm headset spanner and a lockring spanner; 13 and 15 mm spanners, sockets and a screwdriver; tire levers; chain tool; spoke key; spring balance or scale to 30 kg; stopwatch.

**Skills.** Frame building: mitring, brazing or TIG welding chromoly on a jig, and TIG welding aluminium for the rack. Basic metalwork: cutting, drilling, tapping, filing a slot. Bicycle assembly: headset, bottom bracket, wheels, chain and brakes. A local frame builder can make sections 3.1 to 3.8; any bicycle mechanic can do section 4.

**Workspace.** A metalwork bench with the frame jig; a ventilated brazing and welding area away from anything that burns; a clean assembly bench with a bicycle repair stand.

**Personal protective equipment.** Welding helmet, gloves and leather apron for brazing and welding; safety glasses for cutting, drilling and filing; hearing protection when cutting tube; gloves when handling cut tube and plate; no gloves near a turning drill.

## 8. Where the numbers come from

- Model and constructability checks: `cad/src/model.py` (`python cad/src/model.py --check`, 66 checks); STEP and STL exports in `cad/step/` and `cad/stl/`.
- Pictures: `cad/src/build_plan_media.py`, using `.kit/build_views.py`; written to `docs/05-build-plan/` and `cad/drawings/GRR-DWG-101` to `GRR-DWG-108`.
- General arrangement: `cad/drawings/GRR-DWG-001.pdf`, Rev P4.
- Calculations: `docs/04-calcs/01-sizing.md` (GRR-CAL-001 v0.4) and `docs/04-calcs/sizing.py`; fit [A], reach [B], crown clearance and caliper reach [C3], mass [D], rack [E], braking [F], fit change [H], cost [J], strength [K].
- Bill of materials: `bom/bom.csv`.
- Decisions: `docs/decisions/0003-design-for-construction.md` (GRR-DDR-003), with GRR-DDR-001 and GRR-DDR-002; open items in `docs/06-design-decisions.md` (GRR-DEC-001).
- Requirements: `docs/03-requirements.md` (GRR-REQ-001 v0.6).

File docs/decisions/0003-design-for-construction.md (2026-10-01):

---
doc_id: GRR-DDR-003
title: GrowRider design for construction
project: GrowRider
doc_type: Design decision record
version: "0.2"
status: Draft
date: '2026-10-01'
author: Amish Chadha
license: CERN-OHL-S-2.0
revisions:
- version: "0.1"
  date: '2026-10-01'
  author: Amish Chadha
  change: Changes that make the concept physically buildable, with the reason for each; made under Amish's 2026-09-30 instruction to make the design physically buildable; open for his review
- version: "0.2"
  date: '2026-10-01'
  author: Amish Chadha
  change: Accepted by Amish, including the recommendations for A1 to A3
---

# 0003: Design for construction

- **Date:** 2026-10-01
- **Status:** accepted. Amish, 2026-10-01: "i agree with your recommendations for both GrowRider and GravitySort". This covers every change in Tables 1 and 2 and the recommendations in Table 3 (A1 to A3), which are now decided as recommended and recorded in the design decisions register (GRR-DEC-001).

## Context

On 2026-09-30 Amish approved the build plan format and asked for it on every repo, writing: "If you are realising that the design cannot be built as per concept - fix the design assumptions to match and be physically feasible as you draw the illustrations." The TRL 3 model of GRR-DDR-002 showed what GrowRider does and carried its calculations, but it was a massing model: several parts could not be made, fitted or fixed as drawn. Checking the model with build123d found the seventeen problems below.

The changes keep what the bike does: the same wheels, frame geometry, fit range (saddle 400 to 670 mm, 100 mm insertion), bar heights and reach (the grips move less than 2 mm), standover, brakes, rack size and rating, fenders and parts list. Nothing here changes the pitch. Every change is in `cad/src/model.py`, which now builds each component separately (`build_components`) and runs 66 constructability checks (`python cad/src/model.py --check`): fits between sliding parts, the stop positions, parts that must touch, and clearances between parts that must not. All 66 pass.

## Decision

*Table 1. Changes made to the model, the BOM and the calculations.*

| # | Problem in the concept | Change made | Why this way |
| --- | --- | --- | --- |
| P1 | Rear dropouts were plain 40 x 5 x 40 mm blocks 105 mm apart, with no slot. A single-speed coaster hub must slide back to tension its chain, and roadster coaster hubs are about 110 mm over the locknuts. | Track-end dropouts cut from 6 mm steel plate, slot 10 mm wide open to the rear, inner faces 110 mm apart, an M5 eyelet 18 mm behind and 20 mm above the axle. The chainstay ends 40 mm ahead of the axle and the seat stay 16 mm ahead and 20 mm above it, each slotted over the plate and brazed. | The usual single-speed arrangement on roadsters; one plate shape for both sides, mirrored. The eyelet carries the rack strut and fender stay. |
| P2 | Fork blades ended at the axle center with no fork ends. | The bought fork is specified with slotted fork ends 100 mm apart and M5 eyelets (BOM line 2). | Standard on 20 in forks; the eyelets carry the front fender stays. |
| P3 | The coaster brake arm ended in mid-air and ran into the left chainstay. | The arm runs forward under the left chainstay and is held 135 mm ahead of the axle by a bought arm clip: a band round the stay, two legs either side of the arm, one M6 bolt (BOM line 19). | The brake's reaction torque must go into the frame; a clip is how roadsters do it and needs no brazed fitting. |
| P4 | The 34 x 1.5 mm head tube had a 31.0 mm bore; 1 in press-in headset cups need 30.0 mm (JIS). | Head tube 34 x 2.0 mm chromoly, 30.0 mm bore, reamed and faced after brazing. | Fits the common 1 in roadster headset without shims. +0.06 kg. |
| P5 | A 22.2 mm quill cannot slide in a 25.4 x 1.6 mm steerer, whose bore is also 22.2 mm. | Quill 22.0 x 2.0 mm chromoly (a standard metric tube), 0.2 mm diametral clearance; stress at full extension 79 MPa against the 90 MPa screen (77 MPa before) [K2]. | Keeps the decided steerer (GRR-DDR-002, D10). 22.0 mm quills are the other common 1 in size. |
| P6 | The stem head was a block at 0 mm or a tube at 60 mm: no single part does both, and a bar clamp over the quill axis would cover the expander bolt. | A 10 mm chromoly head plate, 127 x 44 mm, welded across the front of the quill, its top flush with the quill top, with four tapped M8 holes at each of two positions. A two-piece aluminium bar clamp block (54 x 44 x 30 mm) bolts to it with four M8 x 40 bolts (13 mm heads) through both halves, putting the bar 45 or 105 mm ahead of the steering axis. The bar sweep becomes 205 mm (from 160) and its rise 15 mm (from 25), and the quill's lowest exposure 20 mm (from 15), so the plate clears the locknut by 2 mm and the grips sit within 2 mm of where the concept had them. Head plate stress 71 MPa against 90 [K6]. | The reach and bar heights of GRR-CAL-001, Section B are unchanged, and the bar position still changes with the 13 mm spanner of R9a. The expander bolt stays reachable from the top with a socket. Moving the block means four bolts; the 1.5 minutes allowed for it in the fit-change estimate [H1] is kept but is tight. |
| P7 | The seat stays met the seat tube 260 mm up, inside the 14 mm band where the clamp collar sits. | The stays end on a cross bar 235 mm up the seat axis (P10), 22 mm below the collar. | The collar must close on a plain tube. |
| P8 | The concept named "positive stop bolts" for the sliding parts but gave no way to fit one. | An M5 dog-point stop screw in each clamp collar, through a hole in the tube below, rides in a 6 mm slot on the side of the part inside: the seat tube collar's screw (left) in a 136 mm slot in the sleeve, the sleeve collar's screw (right) in a 146 mm slot in the post. The lower end of each slot stops its part with exactly 100 mm inserted. The seat tube screw's tip enters the sleeve slot 1.5 mm and stays 0.6 mm clear of the post. | A positive stop that a child or parent cannot pull past, made with a drill and a file. The screws also key the post so the saddle stays straight. The slots lie on the neutral axis of fore-and-aft bending and lower the stiffness by under 1 % [K7]. The quill cannot take a stop of this kind (A1). |
| P9 | The rack struts ended in the air near the axle and its stays in the air by the seat stays. | Struts end in 3 mm tabs bolted to the dropout eyelets; stays end in tabs bolted to M5 bosses brazed on the seat stays. | Four bolted points, all reachable with the wheel in place. |
| P10 | The 64 mm rear fender crossed the seat stays where they were about 50 mm apart, and its front end ran into the chainstays. | The seat stays meet a 16 mm cross bar behind the seat tube that holds them 80 mm apart at the top; the fender's front end starts 10 degrees above the axle line instead of at it; a 12 mm bridge between the stays carries the fender's top bracket; wire stays go to the dropout eyelets. | Full coverage over the top and back of the wheel is kept; 4.8 mm clearance to the frame. |
| P11 | At the smallest setting the saddle sat inside the front of the rack. | Rack platform lowered 30 mm, to 545 mm above the ground: the saddle clears it by 37 mm at the lowest setting and the rack clears the fender by 20 mm. | Same 300 x 120 mm platform and 10 kg rating; slightly lower load. Rail stress unchanged (26 MPa). |
| P12 | The kickstand floated beside the chainstay. | A 4 mm kickstand plate brazed under both chainstays 55 mm behind the BB; a bought centre-mount kickstand clamps to it with one M10 bolt, leg on the left. | The kickstand bosses named in BOM line 1, made concrete. |
| P13 | The calculation measured the fork crown from its top face (26 mm above the tire); the crown is about 22 mm deep, so its underside was 16 mm above the tire and the 16 mm fender gap plus a 3 mm fender would not fit under it. | Fork crown specified about 16 mm deep; front fender 12 mm off the tire (the rear stays at 16 mm). The crown underside is 22 mm above the tire and the fender clears it by 7 mm [C3]. | The only way to keep a front fender under a stock-height crown; the rainy-season mud gap is a little smaller at the front (still at least as large as the 6 mm the concept quoted at the crown). |
| P14 | The front caliper was a box with no reach given. | A long-reach side-pull caliper with about 84 mm reach, on a nutted bolt through the crown; the front fender bracket goes on the same bolt behind the crown. | The reach follows from the crown height and tire size. A caliper of this reach has to be found (register, to confirm). |
| P15 | The down tube met the head tube 1.7 mm below its lower end, where the headset cup presses in. | Down tube moved 5 mm up the head tube; it now ends 3.2 mm above the lower end. | The cup needs a clean, round end to press into. |
| P16 | With a 48 mm chain line the sprocket ran into the drive-side chainstay end and the chain rubbed the seat stay. | Chain line 42 mm; chainstays 21 mm each side of center at the BB. Clearances: sprocket 5.0 mm, chainring 2.4 mm, chain 2.2 mm to the frame; rear tire 4.0 mm to the stays. | A normal single-speed chain line. |
| P17 | The chainguard was a loose plate. | Mounted by a clip round the seat tube and a tab to an M5 boss brazed on the drive chainstay; it clears the chain by 3.9 mm and the crank by 2.0 mm. | As on roadster chainguards. |

*Table 2. Knock-on changes.*

| Item | Change | Reason |
| --- | --- | --- |
| Mass | 14.4 to 15.1 kg (R5 production goal 13 kg, still not met) [D3]: dropouts 0.31 kg, kickstand plate and bosses 0.10 kg, heavier head tube 0.06 kg, stay cross bar and bridge 0.07 kg, collars 0.12 kg, the stem's head plate and clamp block 0.37 kg more than the concept's head; seat stays and chainstays are shorter. | Parts added for construction. |
| Cost | BOM lines 1, 5, 12 and 19 repriced: bike USD 281 to 299, with helmet USD 293 to 311. Value-engineering target USD 300 (`budget_usd` unchanged): the bike is USD 1 under it and the bike with the helmet USD 11 over it [J1]. | Parts added for construction. |
| Braking | Smallest rider, coaster 0.23 to 0.22 g; wet front 0.15 to 0.14 g; both brakes 0.47 to 0.46 g [F2] to [F4]. R7 stays at risk. | Heavier bike. |
| Drawing | GRR-DWG-001 Rev P4; making sketches GRR-DWG-101 to 108 added. | Follows the model. |
| Documents | GRR-CAL-001 v0.4, GRR-PRC-001 v0.6, GRR-REQ-001 v0.6: mass, cost, crown clearance, quill and stem figures updated. No requirement changed status. | Follows the model. |
| Media | Concept media regenerated from the model. The photoreal renders (`media/render-*.png`), `media/card.png` and `media/social-preview.png` still show the concept stem head, dropouts and fittings and need regenerating on Amish's Mac; `cad/src/product_model.py` reads the changed parameters but has not been re-run. | Blender is on the Mac. |

*Table 3. Items that change what the bike does or its safety case: proposed, then accepted by Amish as recommended on 2026-10-01.*

| # | Question | Options | Recommendation |
| --- | --- | --- | --- |
| A1 | The quill cannot take a positive stop like the seat post's: the whole of its inserted length is inside the threaded steerer, under the headset locknut. The concept's safety section says every sliding part has a positive stop. | (a) the minimum insertion mark only, as on every quill stem, checked at each fit change; (b) a steerer 15 mm longer, standing above the locknut, with a clamp-on stop collar whose screw rides in a slot in the quill (the bar sits 14 mm higher at every setting); (c) a stop cable inside the steerer from the crown to the wedge. | (a) for the prototype, with a bright painted band above the mark; decide (b) after the fit trials. |
| A2 | The parts added for construction make the bike 0.7 kg heavier (15.1 kg against the 13 kg production goal). | (a) accept for the prototype and weigh it at TRL 4; (b) look for savings now (for example a lighter head plate design). | (a). |
| A3 | Steerer strength (GRR-DDR-002, N2) now interacts with the quill: a 25.4 x 2.0 mm wall leaves a 21.4 mm bore that no quill fits, and at the lowest setting the quill reaches the crown, where the steerer is most stressed. | (a) keep the 1.6 mm wall and let the ISO 4210-2 fork test decide; (b) a butted steerer thick only inside the crown, with the quill's lowest position raised 20 mm (the bar cannot go as low by 19 mm); (c) a 1 1/8 in steerer with a 25.4 mm quill (less common headset). | (a). |

## Consequences

- `design_state: constructable` in `project.yaml`. The build plan GRR-BLD-001 shows every component and step in pictures generated from the model (`cad/src/build_plan_media.py`), and the design decisions register GRR-DEC-001 carries the open items.
- With A1 accepted, the quill's limit for the prototype is its minimum insertion mark with a bright painted band above it (build plan GRR-BLD-001, section 3.6 and safety stop S4); the stop collar of option (b) is to be decided after the fit trials. With A2 and A3 accepted, the prototype is weighed at TRL 4 and the ISO 4210-2 fork test decides the steerer.
- Requirement status is unchanged: 1 not met (R5), 4 at risk (R7, R9, R11, R12), 2 not verifiable at TRL 3, 5 met (GRR-CAL-001 v0.4).
- Several bought parts set dimensions in the model and must be checked when bought: the coaster hub (110 mm over the locknuts, 42 mm chain line), the caliper reach, the fork's crown depth, steerer length and fork ends, the tire's real width and the 29.8 mm collar closing on the 29.2 mm sleeve. They are listed in the register.
- Nothing has been built or tested; TRL 4 remains on hold by Amish's instruction.

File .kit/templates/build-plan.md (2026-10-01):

---
doc_id: PRJ-BLD-001
title: Project prototype build plan
project: Project name
doc_type: Build plan
version: "0.1"
status: Draft
date: YYYY-MM-DD
author: Amish Chadha
license: CERN-OHL-S-2.0
revisions:
  - version: "0.1"
    date: YYYY-MM-DD
    author: Amish Chadha
    change: First build plan; design made constructable
---

# Project prototype build plan

**Plan, not yet built.** How to build the first proof-of-concept prototype, component by component. Building and testing to it is TRL 4 work. Decisions still to be made are kept in the design decisions register (`docs/06-design-decisions.md`), not here.

## 1. What you are building

Every component, pulled apart and numbered in build order

One short paragraph: what the prototype is, how many components, which are made and which are bought, and the main ways they are made.

## 2. What changed to make it buildable

| Component | The concept had | The buildable design has | Why |
| --- | --- | --- | --- |

## 3. Making the components

### 3.1 Component name

Making sketch

**What it is and what it is made from.**

**How to make it.**

1. Mark out ...
2. Cut ...

**How it fits the parts next to it.**

Close-up of the joint

**Check before moving on.**

## 4. Putting it together

### Step 1: ...

Step 1

## 5. First checks

| Check | Requirement | How | Pass when |
| --- | --- | --- | --- |

## 6. Safety stops

## 7. Tools, skills and workspace

## 8. Where the numbers come from

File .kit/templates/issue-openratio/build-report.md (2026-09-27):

---
name: Build report
about: Tell us what happened when you built, printed or tested part of this design
title: "Build report: "
labels: build-report
---

This is a research and educational prototype, not a medical device. It is a TRL 3 concept and is not released for fabrication. If you build any part of it, you do so at your own risk. Reports help everyone.

**What you built** (part, sub-assembly or test)

**Materials, tools and settings**

**What worked**

**What did not work, with photos or measurements if you have them**

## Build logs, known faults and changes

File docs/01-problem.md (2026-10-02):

---
doc_id: GRR-PRB-001
title: GrowRider problem statement
project: GrowRider
doc_type: Problem statement
version: "0.7"
status: Draft
date: '2026-10-02'
author: Amish Chadha
license: CERN-OHL-S-2.0
revisions:
- version: "0.1"
  date: '2026-09-24'
  author: Amish Chadha
  change: Initial scaffold
- version: "0.2"
  date: '2026-09-24'
  author: Amish Chadha
  change: Populate to TRL 2 (users, context, constraints, out of scope, prior work)
- version: "0.3"
  date: '2026-09-25'
  author: Amish Chadha
  change: TRL 3 update (standard classification checked; open partner and region questions kept open per GRR-DDR-001)
- version: "0.4"
  date: '2026-09-25'
  author: Amish Chadha
  change: Recommendations accepted by Amish (DDR-002)
- version: "0.5"
  date: '2026-09-26'
  author: Amish Chadha
  change: Budget top-up approved by Amish
- version: "0.6"
  date: '2026-10-01'
  author: Amish Chadha
  change: Budget stated as a value-engineering target (Amish, 2026-10-01)
- version: "0.7"
  date: '2026-10-02'
  author: Amish Chadha
  change: First candidate partner (World Bicycle Relief) and first candidate region (Zambia), as decided by Amish on 2026-10-02
---

# GrowRider problem statement

Many rural children in sub-Saharan Africa and other low-income regions walk an hour or more each way to school, and the bicycles that could cut that time do not fit them: adult roadsters are too big, and imported children's bikes are light-duty, outgrown in two or three years and built from parts that local mechanics do not stock.

## The problem

A 5 km walk to school takes 60 to 75 minutes each way at 4 to 5 km/h. That is two to two and a half hours a day spent walking, often in heat, before and after a full school day. Distance is a known reason for late arrival, fatigue and dropout, especially for secondary-school girls, whose schools tend to be farther away.

Bicycles already help. Adult roadster bicycles are the working vehicle of rural East and Southern Africa, and programs such as World Bicycle Relief distribute rugged roadsters (the Buffalo bicycle) to students, health workers and farmers. But a roadster with 28 in wheels is sized for teenagers and adults. Younger and smaller children either walk, ride a bike that is far too big (unable to reach the ground or the brakes safely), or ride a cheap imported children's bike that breaks on rough roads and cannot be repaired with the parts sold in the local market.

A family that does buy a children's bike also faces growth: a child outgrows a fixed-size frame within two or three years, so the bike is either too small for the child who owns it or too big for the younger sibling who inherits it.

## Users and context

| User | Need | Context |
| --- | --- | --- |
| Child rider, ages about 6 to 14 (1.10 to 1.65 m) | A bike that fits now and keeps fitting; easy to stop; comfortable for 5 to 10 km a day; can carry a school bag | Dirt and gravel roads, sand, ruts, mud in the rainy season, shared roads with trucks and motorbikes |
| Parent or guardian | A durable, affordable bike that serves several children in turn; simple adjustment at home | Low and irregular cash income; siblings of different ages share one bike |
| School | Safe arrival of riders; secure parking; a teacher who can check fit and brakes | Rural primary and secondary schools, often 3 to 10 km from home |
| NGO or bicycle distribution program | A children's model that fits its existing supply chain, mechanic training and spare-parts network | Programs that already distribute adult roadsters to students and workers |
| Local mechanic | Parts that are already on the shelf; repairs with the tools already in the kit | Roadside and market stalls with spanners, pliers, a pump and roadster spares |

Context that shapes the design:

- **Rough roads.** Corrugated dirt, loose gravel, sand patches and ruts. Wheels, rims and the frame take repeated impacts, and braking grip is poor on loose surfaces.
- **Heat and dust.** Air temperatures of 35 °C or more, strong sun on black saddles and grips, and fine dust that works into bearings and sliding joints.
- **Thorns.** Acacia and similar thorns cause frequent punctures, and a flat tire far from a pump ends the day's riding.
- **Sharing and growth.** One bike may serve a 6-year-old and a 12-year-old in the same year, and pass down the family over ten years. Fit must change quickly, many times, without special tools.
- **Load pressure.** Children are often asked to carry siblings, water or goods. The rack must be rated low and marked clearly so the bike is not used as a cargo vehicle by or for children.

## Constraints

- Garage-buildable prototype, using a steel frame and bought-in bicycle components. Value-engineering target: USD 300 (`budget_usd` in `project.yaml`, raised from USD 250 on 2026-09-26; a hypothetical control target, not a limit, Amish, 2026-10-01). Estimated cost of the constructable design: USD 299 for the bike (USD 1 under the target), USD 311 with a helmet (USD 11 over).
- Wear parts should be the same as those used on the region's adult roadsters, so local mechanics can repair it with parts already on sale.
- Adjustment and routine service with basic hand tools (open-ended spanners and a screwdriver).
- Child safety comes before carrying capacity: two independent brakes, reflectors, a chainguard and a low rack rating.
- Designed primarily for the school commute. It is not a cargo or water-hauling bike.

## Out of scope

- Carrying passengers, water containers or loads above the rack rating.
- Electric assist, gears or suspension.
- Riders under about 1.10 m (balance bikes serve that group) or adults.
- Manufacturing, distribution financing and the school programs that would use the bike. These belong to partners.

## Prior work

- **Buffalo bicycle (World Bicycle Relief).** A rugged adult roadster designed for rural Africa, with a strong steel frame and a regional spare-parts and mechanic network. It is the reference for durability and parts commonality, but it is too large for young children.
- **Bicycle-for-school programs.** Programs in several African countries give bicycles to students, and a large state program in Bihar, India, that gave girls bicycles for secondary school was found to raise girls' enrollment (Muralidharan and Prakash, "Cycling to School," *American Economic Journal: Applied Economics*, 2017).
- **Adjustable children's bicycles.** Several commercial children's bikes in high-income markets offer extendable seat posts, stems or frames. They are mostly aluminum, use lightweight components not sold in rural markets, and are priced well above a roadster.
- **Standards.** ISO 8098 covers safety requirements for bicycles for young children, and ISO 4210 covers city and trekking bicycles for larger riders. The scopes are set by maximum saddle height: ISO 8098 covers bicycles with a maximum saddle height above 435 mm and below 635 mm, and ISO 4210-2 covers larger ones, with young adult bicycles from 635 to 750 mm ([ISO 8098:2023](https://www.iso.org/standard/78085.html), [ISO 4210-2:2023](https://www.iso.org/standard/78077.html)). GrowRider's maximum saddle height is about 890 mm, so it falls under ISO 4210-2 (GRR-CAL-001, section M).

## Open questions

- Which partner to work with first (a bicycle distribution NGO, a rural school network, or a regional bicycle assembler)? Decided by Amish on 2026-10-02: World Bicycle Relief, through its school bicycle programs and field mechanics, is the first candidate to approach, as partner and co-design partner (GRR-DEC-001).
- Which region to design for first? The Buffalo parts ecosystem suggests Zambia, Kenya or Malawi. Decided by Amish on 2026-10-02: Zambia is the first candidate region (GRR-DEC-001).
- How common is carrying a sibling on the rack, and what design cues (rack size, marking, no footrests) discourage it best? To learn in co-design.
- Would the smallest riders prefer a flat, low handlebar to the swept-back bar, whose grips sit 128 mm above the saddle at the smallest setting? A co-design question, decided by Amish on 2026-09-25 (GRR-DDR-002, D13).
- Can local frame builders work chromoly tube and weld aluminium, as the decided materials require (GRR-DDR-002, D7)? To learn with the partner.

## User research and co-design

This design is for communities the author is not part of, so requirements come from the people who will use it.

- [ ] Identify a local partner organization (Helpful Engineering network, NGO or university)
- [ ] Run co-design sessions with intended users; record who, where and what was learned
- [ ] Validate load, distance, terrain and cost assumptions in the field
- [ ] Revise requirements (REQ) from findings before freezing the design

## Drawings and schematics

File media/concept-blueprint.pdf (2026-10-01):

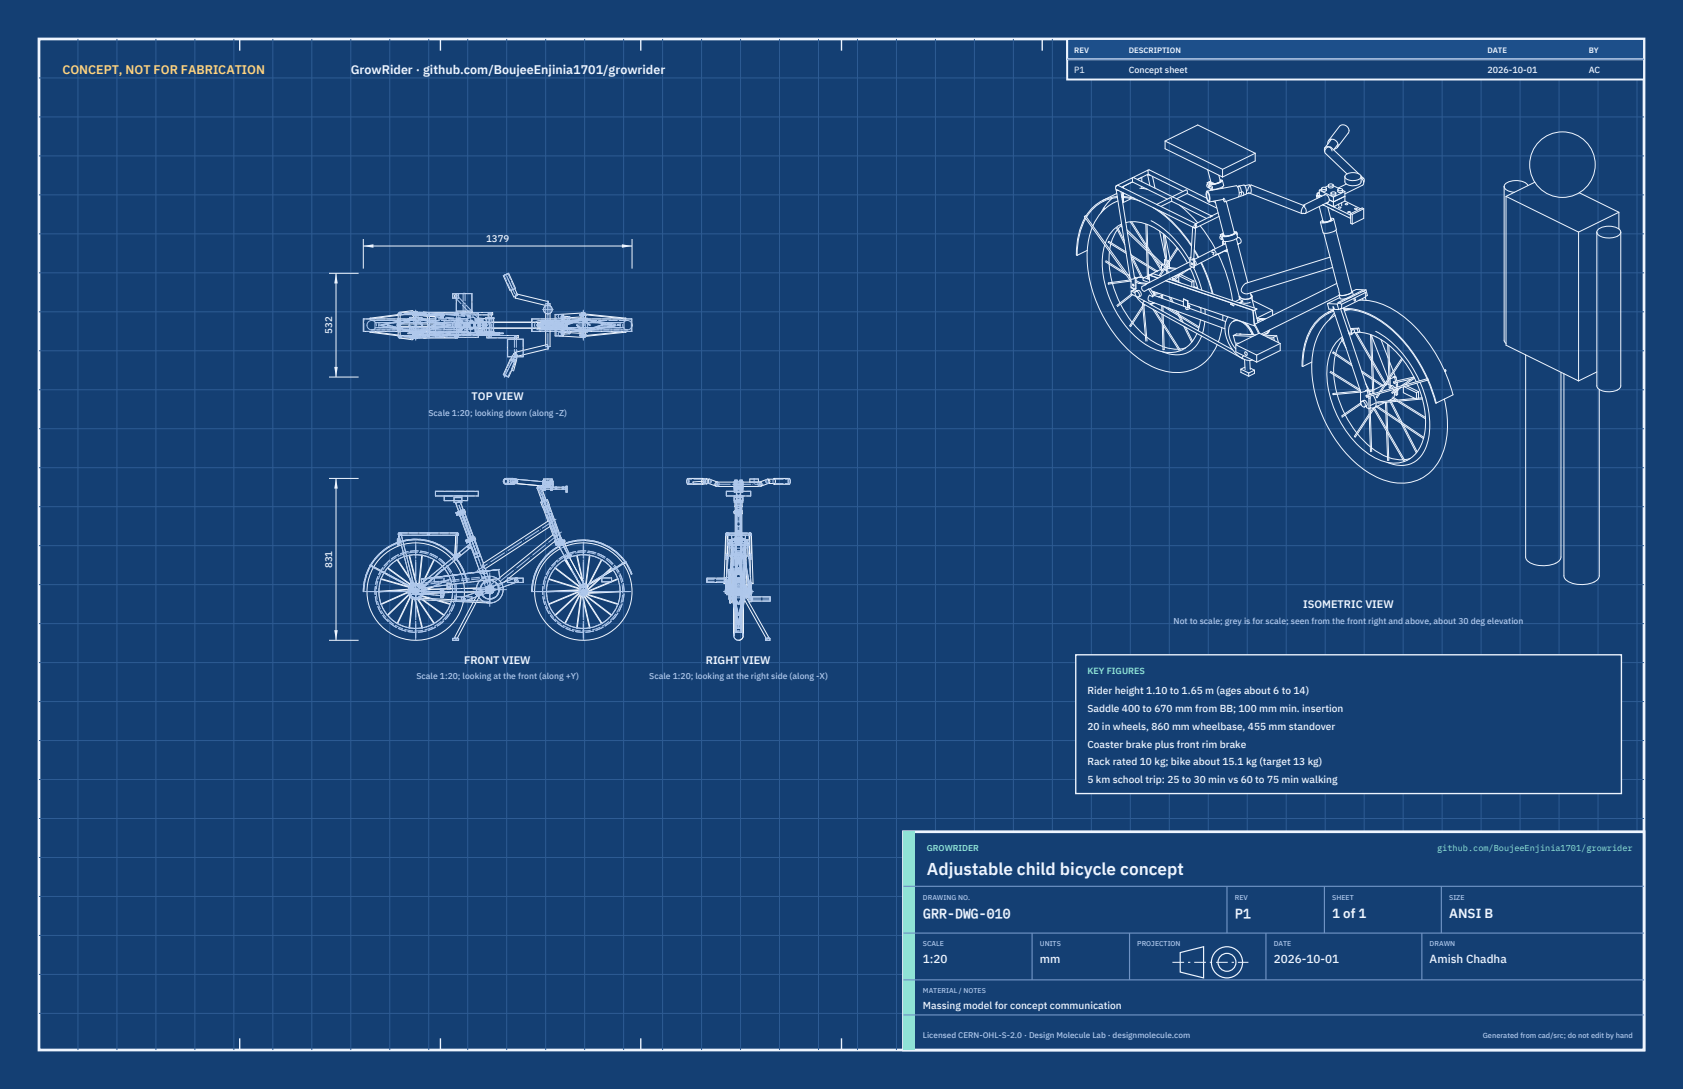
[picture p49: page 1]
CONCEPT, NOT FOR FABRICATION; GrowRider · github.com/BoujeeEnjinia1701/growrider; FRONT VIEW; TOP VIEW; RIGHT VIEW; ISOMETRIC VIEW; REV; DESCRIPTION; DATE; Concept sheet; GROWRIDER; github.com/BoujeeEnjinia1701/growrider; DRAWING NO. GRR-DWG-010; REV P1; SHEET 1 of 1; SIZE ANSI B; SCALE 1:20; UNITS mm; PROJECTION; DRAWN Amish Chadha; Licensed CERN-OHL-S-2.0 · Design Molecule Lab · designmolecule.com; Generated from cad/src; do not edit by hand

Scale 1:20; looking down (along -Z)

Not to scale; grey is for scale; seen from the front right and above, about 30 deg elevation

KEY FIGURES
Rider height 1.10 to 1.65 m (ages about 6 to 14)
Saddle 400 to 670 mm from BB; 100 mm min. insertion
20 in wheels, 860 mm wheelbase, 455 mm standover
Coaster brake plus front rim brake
Rack rated 10 kg; bike about 15.1 kg (target 13 kg)
5 km school trip: 25 to 30 min vs 60 to 75 min walking

Scale 1:20; looking at the front (along +Y)

Scale 1:20; looking at the right side (along -X)

Adjustable child bicycle concept

MATERIAL / NOTES
Massing model for concept communication

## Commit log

2026-09-24 Initial scaffold: standard open hardware layout, CERN-OHL-S v2 + MIT licenses
    Claude-Session: https://claude.ai/code/session_01XuhhSU4W6fYhgCfURbrkut
    [bom.csv]
2026-09-25 Adopt portfolio kit v1.3.0: session commands, scale figure, 3D viewer, flow diagrams
    Adds .claude/commands (/populate, /advance-trl3, /rein-in, /refresh-media)
    so every Claude Code session starts from the standard prompts, and extends
    concept media with a 1.75 m scale figure, an interactive glTF viewer and
    system or energy flow diagrams. TRL cap 3 unchanged.
    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
2026-09-25 Kit v1.3.1: renderer fixes from the TremorTrace pilot
    Context scale parts for small objects, cutaway exclusions, and text
    labels in flow diagrams.
    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
2026-09-25 Populate growrider to a strong TRL 2 with concept media (batch 2)
    Problem, requirements and precis v0.2, massing model and concept media,
    indicative BOM, docs/REVIEW.md with decisions proposed and awaiting Amish.
    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
    [bom.csv]
2026-09-25 Advance growrider to TRL 3 (batch 2)
    Decisions approved by Amish 2026-09-25 recorded in DDR-001. TRL 4 is on hold.
    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
    [bom.csv, fork.step, fork.stl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]
2026-09-26 Accept all recommendations (DDR-002), switch footer to designmolecule.com, add README write-up with new inspiration point
    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
    [bom.csv, fork.step, frame.step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]
2026-09-27 Product appearance model and photoreal renders
    Adds cad/src/product_model.py (appearance model for renders only, all main
    dimensions from model.py) and Blender renders in media/render-*.png,
    captioned with the project, repository and viewing direction. README leads
    with the product render; trl stays 3.
    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
2026-10-01 Image quality pass: legible exploded views, flow diagrams and drawing sheets
    Kit 1.6.1 image layout: the parts list sits in its own column, number bubbles sit on visible parts and never overlap, small parts get a leader, pictures are cropped to the subject, flow labels keep numbers with their units, and sheet captions and the revision table no longer overprint. Concept images, blueprint and general arrangement sheet regenerated; repo-specific labels moved clear of other text and lines.
2026-10-01 Kit 1.7.0: constructable design, illustrated build plan and design decisions register
    The design is now constructable: every part can be made and fits its neighbours, with each change recorded in a Design for construction decision record (made under Amish's 2026-09-30 instruction; ope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
    FlexHand also credits Dr. Geeti Chadha as a contribut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
    [bom.csv, fork.step, fork.stl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]
2026-10-01 Record Amish's 2026-10-01 decisions
    GrowRider and GravitySort: Amish accepted the recommendations in the design decisions register ("i agree with your recommendations for both GrowRider and GravitySort"). Accepted items, including the 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
2026-10-02 Record Amish's approval of the open-decision recommendations
    Amish approved the recommendation on every open decision in the design decisions register ("i approve your recommendations for all 555 open decisions.", 2026-10-02). Each decision is moved to Decisio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
    [bom.csv]
2026-10-03 Carry approved follow-ups into the design and redo photoreal renders
    Amish approved the follow-up actions from the open-decision sign-off ("APPROVED CHANGES, COMPLETE THESE", 2026-10-02), the design-for-construction change tables in ten repos, the last wave's open dec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

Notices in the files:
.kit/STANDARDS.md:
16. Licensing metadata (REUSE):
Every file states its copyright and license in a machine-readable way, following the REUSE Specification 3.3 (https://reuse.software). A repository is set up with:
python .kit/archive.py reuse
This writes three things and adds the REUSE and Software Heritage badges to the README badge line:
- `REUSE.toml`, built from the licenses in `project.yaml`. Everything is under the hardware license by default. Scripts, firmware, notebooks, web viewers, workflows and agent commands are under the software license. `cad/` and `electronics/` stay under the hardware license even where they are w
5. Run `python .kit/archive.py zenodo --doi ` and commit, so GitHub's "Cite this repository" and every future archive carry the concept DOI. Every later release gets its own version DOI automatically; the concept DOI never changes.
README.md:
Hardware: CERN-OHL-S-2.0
